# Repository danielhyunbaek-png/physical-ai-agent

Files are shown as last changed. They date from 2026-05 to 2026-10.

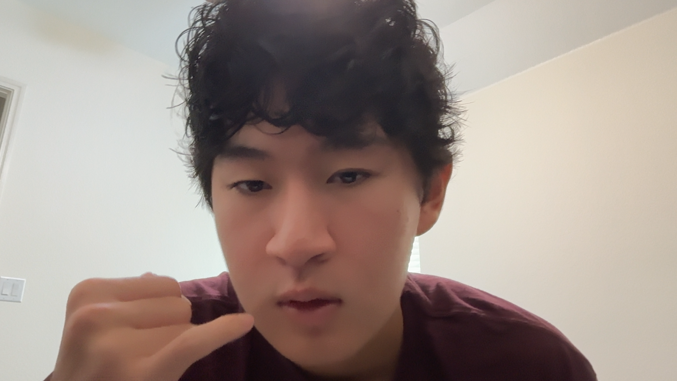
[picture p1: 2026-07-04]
agent/test_frame.png

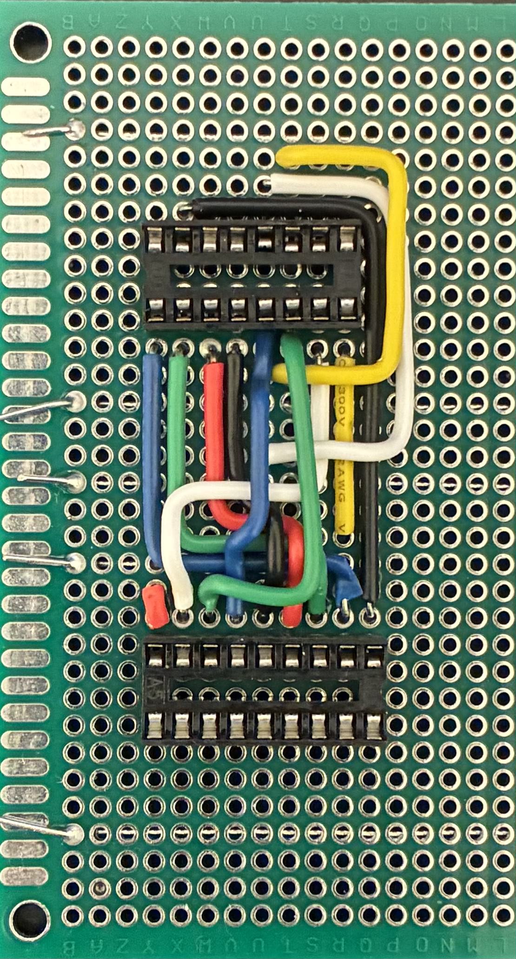
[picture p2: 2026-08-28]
cell1photo.jpg

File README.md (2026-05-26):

Architecture:

The Physical AI Agent I'm currently building is a closed loop system that is made to operate a computer exactly how a human does. It uses visual feedback and physical actuations. The system runs on a discrete time loop across a macOS host and two microcontrollers.

Vision:

- Uses a fixed webcam
- Python based pipeline will capture frames at 30 fps. Each frame is deskewed using a precomputed perspective transform to map the MacBook screen to a fixed 1920x1200 pixel grid. 
- Uses OpenCV template matching for UI elements and Tesseract OCR for text extraction. 

Cognition: 

- Runs on the MacBook Pro
- Python FSM that reads perception stream and executes serial commands. 
- Goal: Under 100 ms from screen change to first physical actuation. 

Action:

-Keyboard: Using the Nuphy Air75 v3 keyboard with Blush Nano switches (45g force, 1.4 actuation).
Using the Arduino mega 2560 with 84 12V micro solenoids (10mm stroke, 5N force), housed in a custom 3D printed matrix plate. 11 cascaded 74HC595 shift resistors feeding 11 ULN2803A Darlington arrays. All powered by 12V PSU with a firmware cap of 12 solenoid activations. 

Mouse: 2 axis XY gantry system controlled by Arduino Uno. Powered by NEMA 17 steppers driven by A4988 drivers. Two SG90 hobby servos providing click actuation.

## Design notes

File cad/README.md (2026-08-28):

# cad/ — Fusion scripts

Fusion has no MCP connector, so CAD works the same way KiCad does: **Daniel
drives Fusion, Claude owns the file and verifies it mechanically.** These
scripts are the mechanism — geometry lives in Python, so every dimension is
reviewable, diffable, and checkable without opening Fusion.

| File | What it does |
|---|---|
| `fusion_groove_coupon.py` | Builds the brief-08 groove coupon (plate section + 2 walls + mini-deck) in a fresh Fusion document. **The teardown gate.** |
| `verify_coupon_geometry.py` | Runs outside Fusion. Asserts every brief-08 invariant, the Jul 27 measurements, CSV key positions, and cross-checks against `Air75_84Key_Plate_Left.stl`. Currently 0 failures. |

## Running the coupon script in Fusion

1. Open Autodesk Fusion. Any document — the script creates its own.
2. **Utilities** tab → **ADD-INS** panel → **Scripts and Add-Ins** (or `Shift+S`).
3. **Scripts** tab → the **+** beside "My Scripts" → **Create from existing** → pick
   `cad/fusion_groove_coupon.py` from this repo.
   *(If Fusion insists on copying it into its own scripts folder, use the green
   `+` → "Link" option so it keeps reading the repo copy and git stays the source
   of truth.)*
4. Select `fusion_groove_coupon` → **Run**. A dialog reports the key dimensions.
5. Four components appear at true assembly coordinates: `Coupon_Plate`,
   `Wall_A`, `Wall_B`, `Coupon_Deck`. **Look at it first** — the walls should sit
   in their plate grooves with the deck grooves capturing their tops.
6. Export each component: right-click component → **Save as Mesh** → STL, or
   **File → Export** → STL with "one file per body" unchecked.

## Verifying before you print

```
python3 cad/verify_coupon_geometry.py
```

Needs `trimesh` and `numpy` for the STL cross-check (`pip install trimesh numpy`);
everything else runs on stock Python. Exit code 0 = all invariants hold.

## Slicer notes

| Part | Orientation | Notes |
|---|---|---|
| `Coupon_Plate` | flat, as modelled | groove floor is only 2mm — don't skimp on top layers |
| `Wall_A` / `Wall_B` | **lay flat on the wide face** | 58mm tall × 2.5mm thin section; printing upright makes a fragile fin and puts layer lines across the load path |
| `Coupon_Deck` | flat | grooves face up or down, doesn't matter at 2mm |

Same material and same nozzle/layer settings as the 84-key plate print — the
whole point is that the groove fit transfers to the real part.

## The test sequence (brief 08 §Stage 1 item 7)

1. Heat-set an M3 insert into each wall's boss.
2. Screw one solenoid to each wall **on the bench** — full access, no slot-driving.
   Use the M3×3 flat heads, counterbores facing the back.
3. Drop each wall+solenoid into its plate groove, plungers entering their Ø10
   holes first. Check: does the datum face seat? Does the groove bind or rattle?
4. Mini-deck on, 2 × M3×8 down into the inserts.
5. **Check the flare clears the back row's spring** — Wall_A's flare passes
   within 1.0mm of Wall_B's solenoid spring. This is the one clearance derived
   from an estimated spring OD rather than a measurement.
6. Fire both solenoids off the breadboard driver, deck installed.
7. One full swap cycle: deck off, wall out, swap the solenoid, back in.

**Pass = the old plate teardown is authorised.** Fit fail = change
`GROOVE_CLEARANCE` at the top of the script by ±0.05–0.10, re-run, reprint the
coupon only.

## Tuning log

Record each printed value here so the winning number is never re-guessed.

| Date | `GROOVE_CLEARANCE` | Plate groove | Deck groove | Result |
|---|---|---|---|---|
| — | 0.25 | 2.75 | 5.30 | not yet printed |

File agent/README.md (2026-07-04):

# Agent software — observe → decide → act

The complete software stack for the physical agent, every layer testable
**without any hardware** (campsite rule, July 2026: exercise everything on
the MacBook alone, then point it at the real rig at home).

| File | What | Hardware needed |
|---|---|---|
| `keyboard_driver.py` | Python wrapper for the `keyboard_v1` serial protocol | None (dry-run) → Mega later |
| `mouse_driver.py` | Mouse backends: dry / **mousekeys** / gantry | mousekeys needs only the keyboard! |
| `actions.py` | One action vocabulary: validation + dispatch | None |
| `vision.py` | Capture → rectify → template match + OCR + frame hashing | Mac camera, or `still=` a PNG |
| `llm.py` | Pluggable brain + retries + JSON repair + $ metering | None |
| `runtime.py` | Session engine: logging, budgets, stuck detection, escalation | None |
| `agent_loop.py` | General-goal CLI over the runtime | None (`--dry-run --scripted`) |
| `calibrate.py` | screen / tft / gantry / mousekeys calibration flows | Varies |
| `tft/` | TFT layer: layout, set data, semantic actions, `play_tft.py` | None to rehearse |
| `tests/run_tests.py` | 20-test ladder for all of the above | **None at all** |

## The one command that proves the plumbing

```bash
cd agent && source .venv/bin/activate
python tests/run_tests.py        # 20 tests, no hardware, no network, no keys
```

If that passes, what's left to trust is physics and prompt quality.

## Choosing a brain (`--provider`)

| Provider | Cost per ~700-turn TFT game | Needs |
|---|---|---|
| `ollama` | $0 (local Qwen3-VL) | `brew install ollama && ollama pull qwen3-vl:8b` |
| `gemini` / `deepseek` / `qwen` | ~$0.10–0.50 | API key env var (see `llm.py` header) |
| `anthropic` | ~$4–8 | `ANTHROPIC_API_KEY` |

Strategy: **develop on `ollama`, play on cheap cloud, escalate hard turns.**
`--escalate-to anthropic` lets the cheap brain hand up any turn it flags with
`"escalate": true` (augment choices), and `--budget-usd 1.00` hard-stops the
session at the estimated spend.

## Choosing a mouse (`--mouse`)

| Backend | What moves the cursor | Hardware |
|---|---|---|
| `none` (default) | nothing — keyboard-only goals | Wave 1 |
| `dry` | print statements | none |
| `mousekeys` | **macOS Mouse Keys pressed by the solenoids** | Wave 1 only! |
| `gantry` | XY gantry + click servos (`firmware/mouse_gantry_v0`) | Wave 2 |

`mousekeys` is the sleeper: enable Mouse Keys on the target Mac
(Accessibility → Pointer Control; also enable the 5×-Option toggle) and the
robot gets real clicking and dragging **before any Wave 2 hardware exists**.
The driver toggles Mouse Keys off around text input automatically. Calibrate
speeds with `python calibrate.py mousekeys`.

## Run recipes

```bash
# plumbing, zero everything
python agent_loop.py --goal test --scripted --dry-run --mouse dry

# real brain, no hardware, on a saved screenshot
python agent_loop.py --goal "describe the screen" --dry-run \
    --still shot.png --provider ollama

# real rig, general goal
python agent_loop.py --goal "open spotlight and type hello" \
    --port /dev/tty.usbmodem14101 --calib calibration/screen_quad.json

# TFT rehearsal (no hardware) / TFT for real (cheap + escalation + cap)
python tft/play_tft.py --still tft_shot.png --dry-run --provider ollama
python tft/play_tft.py --port /dev/tty.usbmodemXXXX --mouse gantry \
    --mouse-port /dev/tty.usbserialYYYY --mouse-calib calibration/gantry_affine.json \
    --provider gemini --escalate-to anthropic --budget-usd 1.00
```

Every session writes `logs/session_<ts>/` — `session.jsonl` (plan, actions,
results, cost per turn), the frame each decision saw, and `summary.json`.
That's the replay data for prompt tuning.

## Before real TFT games (checklist)

1. `python calibrate.py screen` — C920 on tripod, bright fullscreen page.
2. `python calibrate.py tft --still <screenshot>` — nudge `tft/layout.json`
   until the dots sit on the shop cards/hexes/buttons.
3. Fill in `tft/set_data.json` for the live set (file explains how).
4. Crop a combat-only UI element into `tft/templates/combat_marker.png` —
   unlocks combat-phase skipping (~70% fewer LLM calls).
5. Mouse: `calibrate.py gantry` or `calibrate.py mousekeys`.

## Setup

```bash
cd agent
python3 -m venv .venv && source .venv/bin/activate   # re-activate EVERY terminal
pip install -r requirements.txt
brew install tesseract        # OCR engine (macOS)
```

### MAP workflow (ties into the solder-time log)

Keep logging `cell,out,key` lines at solder time (MAP discipline: label holes,
not wires). Put them in a CSV, then:

```python
from keyboard_driver import KeyboardDriver, load_map_from_log
kb = KeyboardDriver("/dev/tty.usbmodem14101")
load_map_from_log(kb, "map_log.csv")   # pushes MAP entries + SAVEs to EEPROM
kb.walk()                              # verification pass: watch which key clicks
```

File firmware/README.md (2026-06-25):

# Firmware — Week 2 Breadboard

Two sketches. Build them in order. Each is its own folder so the Arduino IDE is happy.

## 1. `sr_led_walk/` — sanity-check the shift register

Goal: prove one 74HC595 is wired correctly with 8 LEDs before any solenoids exist.

Wiring (74HC595 → Arduino Mega):

| 595 pin | Name  | Goes to |
|---:|---|---|
| 14 | DS | D11 |
| 11 | SH_CP | D12 |
| 12 | ST_CP | D13 |
| 13 | OE | GND |
| 10 | MR | +5V |
| 16 | VCC | +5V (+ 0.1 µF to GND) |
|  8 | GND | GND |
| 15, 1–7 | Q0–Q7 | LED → 330 Ω → GND |

Flash, open Serial Monitor at 115200 — you should see a bit walking left-to-right across the 8 LEDs once per second-ish.

## 2. `keyboard_v0/` — drive 4 solenoids

After the LED walk works, swap the LEDs for the ULN2803A → 4 solenoids.

ULN2803A wiring:

- IN1–IN8 ← 595 Q0–Q7 (one-to-one)
- OUT1–OUT8 → low side of each solenoid coil
- Solenoid high side → +12V rail from PSU
- **COM (pin 10) → +12V** (this enables the internal flyback diodes — do not skip)
- GND (pin 9) → PSU GND **and** Arduino GND (common ground star point)
- 470 µF (or larger) bulk cap across the 12V rail near the ULN
- 0.1 µF decoupling across the 595 VCC/GND

Critical: the Arduino 5V rail and the PSU 12V rail must **not** touch. Only the grounds tie.

Open Serial Monitor at 115200 baud, line ending: Newline. Then type:

```
FIRE 0 50
FIRE 1 50
FIRE 2 50
FIRE 3 50
```

Acceptance: 4 crisp clicks in order. Plungers fully retract between fires. No buzzing, no missed clicks.

Also available: `ALLOFF` (force every channel low — useful if a fire hung).

### Pulse-width tuning notes

- 50 ms is the walkthrough default. Try also 30 ms and 80 ms and listen — Blush Nano switches actuate at ~1.4 mm so 30 ms is often enough once geometry is right.
- The firmware clamps any pulse to 200 ms and enforces a 20 ms gap between fires as a coil-protection guardrail.

### What to measure while the breadboard is live (feeds Week 3 CAD)

1. **Mounting tabs** — confirm 2 vs 4 tab layout and tab-hole spacing (calipers).
2. **Plunger rest extension** — mm of plunger sticking out at rest.
3. **Plunger force at 30 / 50 / 80 ms** — push against a kitchen scale tared to zero.
4. **Body temperature** after firing one solenoid 200× at 50 ms with 100 ms gap. Touch test is fine for now; flag if uncomfortably hot.
5. **End-to-end latency** — toggle a free Mega pin HIGH right before the latch and LOW after, scope or logic-analyzer the pin vs the solenoid current rise (optional, nice to have).

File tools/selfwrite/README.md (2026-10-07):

# selfwrite: the keyboard writes its own software

From the 698-like comment: *"Now let Claude control it and write its own software."*

`gen0.py` (written by a human) asks Claude to write `gen1.py`. **The solenoids type gen1 into Terminal**, then type `python3 gen1.py &`. gen1 now controls the keyboard: it asks Claude for gen2, types it and launches it. **gen3 is the last one** and says goodbye. Each generation gets a GOAL from its parent and has to do one new visible thing.

Safety rails live in `selfwrite.py`, which Claude can't edit:
- Hard stop at gen 3.
- Generated code can only import `selfwrite`, with no os, files or network.
- Code is syntax-checked before it's typed.
- Every typed file is **read back from disk and compared** before it runs.

## 0. One-time setup (~5 min)
```bash
cd ~/"Documents/Claude/Projects/Physical AI Agent/agent" && source .venv/bin/activate
python3 -c "import serial; print('pyserial ok')"
export ANTHROPIC_API_KEY=sk-ant-...     # console.anthropic.com -> API keys
cd ../tools/selfwrite
python3 selfwrite.py preview            # NO typing: prints the gen1 Claude would write
```
If `preview` prints Python code, the API key works.

## 1. Map the keys Python needs (~30–45 min, PSU on only while testing)
```bash
python3 selfwrite.py check              # lists mapped keys + what's missing
```
**Must have:** `Enter LShift 9 0 ; = ' . , -`. All of these are needed for `( ) : = " ' . , _`.
**Should have:** `1–8`, `[ ]`, `/`. Claude is told which characters exist and will avoid the rest.
To map a key: Serial Monitor, `FIRE <ch>`, watch which key moves, then `MAP <ch> <Name>` and `SAVE`. Run `check` again when you're done.
Then a smoke test: open a blank Terminal and type `python3 -c "print('hi')"` with `TYPE` and `KEY Enter`.

## 2. Film
1. Close Serial Monitor and the Monkeytype Chrome tab. They hold the USB port.
2. Use a clean Terminal window with a big font (Cmd +), in `tools/selfwrite` with the venv active. Run `rm -f gen1.py gen2.py gen3.py`.
3. Type yourself: `python3 gen0.py &` and press Enter. **Then hands off.** Keep the Terminal window focused the whole run.
4. Each generation takes about 1–2 min of typing plus 10–20 s for Claude. Total is roughly 5–7 min, so speed it up in the edit.

**If it stops:** `[selfwrite] ... differs` means a key was missed, usually from plate sag. It retries once, then stops. If the shell is stuck in `heredoc>`, press Ctrl-C by hand. For the shot list, the `gen1.py`–`gen3.py` files are the evidence. Open them at the end of the video.

## Env knobs
`CLAUDE_MODEL` (default `claude-sonnet-5-5`) · `KB_PULSE` (50) · `KB_PORT` · `SELFWRITE_MAX_GEN` (3) · `KB_DRY=1 SELFWRITE_FAKE=1 python3 gen0.py` runs the whole chain with no hardware and no API.

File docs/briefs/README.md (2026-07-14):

# Task briefs — pre-loaded prompts for upcoming milestones

Each brief is a ready-to-run session starter written by Fable 5 (July 2026) with full project context baked in. When a session's goal matches a brief, read the brief FIRST — it encodes constraints and failure modes that took weeks to learn.

| Brief | Milestone | Blockers |
|---|---|---|
| `01_cell1_solder_and_first_fire.md` | Solder driver cell #1, cold-continuity gate, first fire from soldered board | Home + hardware |
| `02_walk_map_verification.md` | Flash keyboard_v1, build the MAP via solder-time log, verify with WALK | Cell #1 done |
| `03_84key_plate_cad.md` | Full 84-key plate CAD (the big one) | 2×2 FIRE test passed |
| `04_wave2_mouse_decision.md` | Pick the Wave 2 mouse mechanism (TFT drag requirement) | None — do anytime |
| `05_tft_bringup.md` | First TFT game: calibration → set data → cheap-brain game | Vision + mouse working |
| `06_driver_pcb.md` | Custom driver PCB (replaces perfboard for all 11 cells) + interim breadboard fire test | None — design now, breadboard this week |

Always pair a brief with `docs/PLAYBOOK.md` (reasoning patterns) and CLAUDE.md (current facts). If a brief contradicts CLAUDE.md, CLAUDE.md is newer — trust it and fix the brief.

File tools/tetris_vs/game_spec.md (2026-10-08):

Write a complete two-player VERSUS Tetris game in ONE Python file.

Context: you are playing against a human, the person who just spoke to you. Every
character of your file will be typed by a physical robot keyboard (84 solenoids
pressing real keys), then run. During the game YOU play too, but you can only
act by pressing real keys through those same solenoids, so every move you make
is physically slow and a press can occasionally be missed. Design for that.

## Hard rules (a test harness enforces these)
- Python 3.9. Allowed imports ONLY: pygame, random, math, time, robot.
- ASCII only. 4-space indents, no tabs. Keep lines under 80 characters.
- Keep it SHORT: aim for 7000-8500 typed characters, hard limit 9500
  (leading indentation is free: the editor auto-indents). Each character
  costs the robot ~0.12 s of typing. Very few comments.
- No file, network or OS access. Fonts: pygame.font.Font(None, size) only.
- The window: screen = pygame.display.set_mode(robot.WINDOW)
- Call robot.tick() exactly once per frame in the main loop. 60 FPS clock.
- QUIT event or the Escape key exits cleanly (pygame.quit(), then return).

## The robot module (already exists, do not write it)
    import robot
    robot.WINDOW            # (width, height) for set_mode
    robot.press(key)        # key is one of "J", "L", "I", "K", "Space".
                            # Queues ONE physical key press. Returns True if
                            # queued. Never blocks.
    robot.pending()         # number of presses queued or still in flight
    robot.say(text)         # speaks text out loud in Claude's voice; skipped
                            # (returns False) if it is already talking
    robot.tick()            # once per frame
    robot.report(name, value)   # status for the test harness, see below

## Controls (two keyboards feed the same Mac, so the keys MUST differ)
- HUMAN (left board, Mac's built-in keyboard): Left/Right arrows move,
  Up rotates clockwise, Down soft-drops one row, Right Shift OR Return
  hard-drops.
- CLAUDE (right board, the robot keyboard): J left, L right, I rotate
  clockwise, K soft drop one row, Space hard drop.
- The game moves Claude's piece ONLY when it receives those KEYDOWN events,
  exactly like a human player. Your AI must never move pieces directly.

## Game rules
- Two 10x20 boards. Standard 7 tetrominoes, colored.
- Both players get the SAME piece sequence: one 7-bag sequence per match
  from random.Random(seed), each player has their own index into it.
- Spawn at the top center. Rotation with simple wall kicks (try x offsets
  0, -1, 1, -2, 2). A piece locks when gravity cannot move it down.
- Gravity starts at 0.8 s per row and gets 20% faster every 30 s (min 0.1 s),
  same for both players.
- Clearing n lines: n >= 2 sends n - 1 garbage rows to the opponent (4 lines
  sends 4). Garbage rows are gray, full except one random gap, and are added
  at the bottom of the opponent's board when their next piece spawns.
- If a new piece cannot spawn, that player tops out and the OTHER player wins.

## Screens
- Menu: big title "HUMAN vs CLAUDE", the controls for both players,
  "click to start". A mouse click starts a 3-2-1 countdown, then play.
- Play: HUMAN board on the left, CLAUDE board on the right, names above them,
  lines cleared, next-piece preview for each, match timer in the middle.
- Game over: a big "CLAUDE WINS" or "HUMAN WINS" overlay plus
  "press R for rematch". R starts a new countdown with a new seed and keeps a
  running match score (e.g. "HUMAN 1 - 3 CLAUDE").

## Claude's player (the important part)
- When Claude's piece spawns, pick a placement: for every rotation and every
  x, simulate a hard drop on the current board and score the result with
  -0.51*aggregate_height + 0.76*lines_cleared - 0.36*holes - 0.18*bumpiness.
  Prefer fewer rotations on ties.
- Then each frame: if robot.pending() > 0, or less than 0.2 s has passed since
  your last press, do nothing. Otherwise look at the ACTUAL piece state and
  press exactly one key toward the goal: "I" until the rotation matches,
  then "J"/"L" until x matches, then "Space".
- Never assume a press worked: always decide from the actual state, so a
  missed press is simply repeated and an extra move is corrected. If the
  same press has had no effect 4 times in a row (blocked), press "Space".
- Re-plan whenever a new piece spawns (track a piece counter).

## Trash talk (robot.say)
Write your own short, funny, PG lines (under 12 words each), several
variants per moment, picked at random:
- when the match starts,
- when Claude clears 2+ lines (sending garbage),
- when Claude clears 4 lines at once,
- when the human tops out (Claude wins),
- when Claude tops out (the human wins; be a gracious but salty loser).
Keep it general: call the opponent "human", never use a name, and never
mention who built the robot or anything about its history. Human-vs-machine
banter, and jokes about you moving only by solenoid, are fine.

## Reports for the test harness (required)
    robot.report("state", s)        # s in "menu","countdown","playing","over"
    robot.report("claude_lines", n) # total lines Claude cleared this match
    robot.report("daniel_lines", n)
    robot.report("winner", w)       # "CLAUDE" or "HUMAN", when a match ends

Reply with ONLY the Python code. No markdown fences, no explanation.

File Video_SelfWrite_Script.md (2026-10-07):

# Video: "The keyboard writes its own software" (Oct 6, 2026)

Uses the hook framework: two questions in the hook, answer #1 right away, "but it's not what you think" instead of explaining, real stakes, and a new question at every generation.

## Hook (0–4 s)
VO: "You told me to let Claude control my self-typing keyboard. So now it writes its own code, types it, and runs it."
- **Question 1:** "Can it actually do it?" Answer it immediately: hard cut to solenoids typing code, with the Terminal filling up.
- **Question 2:** "But can it survive 3 generations without one mistake?" Leave it open until the end.

## "But it's not what you think" (4–10 s)
VO: "Everyone in my comments said 'just use a macro.' But this isn't a macro. A macro replays keys someone recorded. Nobody knows what this code says, not even me, until Claude writes it."

## Stakes (10–18 s)
- "One missed keypress is a syntax error, and the whole chain dies."
- "That's about 1,500 keystrokes in a row with zero mistakes, on a plate that sags in the middle."
- "And the last time I left this thing running on its own, it melted a chip." (Show the dead ULN2803A if you still have it.)

## Body: a new question every generation (18–50 s)
- On screen the whole time: `GEN 1/3` and a keystroke counter.
- Before each launch: freeze frame plus "What did Claude make it do?" Then play the result.
- Gen 1 → its new thing. "Then it wrote its own replacement."
- Gen 2 → its new thing. "One more."
- Gen 3 (the last one) → close-up as it types. "Did it make it?"

## Payoff (50–60 s)
- Gen 3's goodbye on screen. Then open gen1–gen3.py side by side: "Nobody touched these keys."
- Close with a comment prompt: "It stopped at gen 3 because I told it to. Should I take the limit off?"

## Honest notes
- If a generation fails on camera, **keep it.** "It died on keystroke 1,102" is a real stake paying off, and it sets up a sequel.
- Don't claim it's dangerous beyond what's true. Its code can't touch your files or the internet; you set it up that way. "I put it in a box" is a good line if comments ask.

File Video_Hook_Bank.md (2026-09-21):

# Video Hook Bank — the comeback video (and every one after)
**Built Sep 21, 2026.** Research-backed hook options matched to footage actually in hand.
Companion to `Video_Scripts.md` and `Social_Media_Strategy.md`. Supersedes the hook line in `Video_Script_Big_Reset.md` (that video posted Jul 30).

---

## What the research actually says

Most "viral hook formula" content online is SEO filler with no data behind it. Two findings survived filtering, and both point the same direction:

1. **"Result First" is the strongest hook type in DIY/Maker specifically** — 84 avg retention score vs 58 for the worst type in the same niche, a 26-point gap. Across all niches it ranked #1 of 8. (Brightbean, 10k-hook analysis. Proprietary scoring, so treat as directional — but it converges with everything else.)
2. **Deliver the complete hook inside 5 seconds.** Videos that did retained ~23% more viewers at the 30-second mark than videos needing 10+ seconds of setup.

Supporting, weaker: blended hooks (two types at once) beat single-type 79 vs 73. And the recurring failure mode across analyses is *setup before claim* — backstory, credentials, context, "so last video I…".

**All of this already agrees with `Social_Media_Strategy.md`:** *"0–2 sec: Visual hook. Show the most impressive thing first. NO intro, NO 'hey guys.'"* The research doesn't change the playbook, it confirms it and tells us which specific asset to lead with.

---

## The structural consequence — this is the important part

"Result First" in a build series that **isn't finished yet** means: open on the most finished-looking working thing you own.

That is the **breadboard fire-test clip** — a solenoid physically pressing a key, a character appearing on screen. It is the only footage in the archive where the machine does the thing.

**So it goes at 0:00, not only at 0:40.** Use it twice:

- **0:00–0:02** — the press, real sound, no music, no talking. Proof before claim.
- **0:02–0:05** — the hook line lands over it or immediately after.
- ...build content...
- **0:38–0:48** — the fuller version of the same clip as the payoff, now that the viewer knows what it cost.

Same shot, two jobs. Opening cold on a black screen or a face is spending the first two seconds on the least interesting frame you have.

---

## HOOK BANK

Each one is tagged with the pattern it copies and the shot it plays over. Every hook should be **spoken AND on-screen as text** — most viewers are sound-off on the first watch.

### Tier 1 — lead with these

**H1 — "This keyboard types by itself."** · *Result First* · over the fire-test press
> Then, after the beat: *"Well — one key does. So far."*

The chosen line, tightened. Present tense beats "is going to" — a promise is weaker than a claim you're about to prove, and you can make the claim honestly because the clip is playing while you say it. The walk-back in the second line is the hook's engine: it converts a flat statement into an open loop (*how far off is he?*) and it's honest, which the rest of the video has to be anyway. Blended: Result First + a soft contrarian turn.

**H2 — "That was a robot pressing that key. I need 83 more."** · *Result First + Shocking Stat* · over the fire-test press
The number does the work without jargon, and it arrives *after* the viewer has already seen one work — so 83 reads as scale, not as noise. Strongest pure-numbers option.

**H3 — "One key down. Eighty-three to go."** · *Result First* · over the press, hard cut to the full plate on the dorm desk
Shortest in the bank — lands in about 1.5 seconds, well inside the 5-second rule, and the cut to 84 solenoids IS the punchline. Best option if you want the song to drop early.

### Tier 2 — strong, different flavor

**H4 — "There's a way to do this in software in about four lines of code. I'm not doing that."** · *Contrarian Claim* (#2 overall in the research) · over the plate overhead
This is the "why" from `Social_Media_Strategy.md` weaponized as a hook instead of buried as an explainer. Pre-empts the top comment, which makes the comments section argue *with each other* instead of with you. Use when you want the thoughtful-engineering audience over the spectacle audience.

**H5 — "Every single key on this keyboard is getting its own robot."** · *Direct Promise* · over a slow push across the populated plate
No jargon, no number required, instantly legible to someone who has never seen the project. The safest cold-start hook for a brand-new viewer — and after 7 weeks off, most of your reach is brand-new viewers.

**H6 — "233 solder joints. That's one board. I need three."** · *Shocking Stat* · over the bare PCB before-shot
Sets up the timelapse better than anything else here, because it makes the viewer want to watch the work rather than skip it. Downside: opens on effort rather than result, which is exactly the trade the research penalizes. Use it as the *second* beat at 0:05, not at 0:00.

### Tier 3 — the gap, handled

**H7 — "Last time you saw this it was a pile of wires on my desk. It's now a pile of wires 900 miles away."** · *Story Setup* · over the dorm desk wide
Addresses the 7-week absence and the move in one line without apologizing. Only use if the dorm-desk frame is genuinely good. Story Setup ranked #3 of 8 — respectable, but it spends the opening on you instead of the machine.

**H8 — "I moved to college and the first thing I unpacked was this."** · *Story Setup* · dorm desk, plate revealed
The salvageable version of the line you rejected. Works because the reveal carries it; the words alone are nothing. Weaker than Tier 1 for reach, better than Tier 1 for the people already following.

### Rejected — do not use

- **"I brought 84 solenoids to college."** Jargon in the first 3 seconds. "Solenoid" means nothing to a cold viewer, so "84" has no weight, and the sentence is about logistics rather than the machine.
- **"How do you make a keyboard type by itself?"** Question hooks ranked mid-pack (#5) and this one has no stakes — it invites the viewer to answer "you don't" and scroll.
- **Anything opening with "Part 6" / "Day 53" / "so in my last video."** Setup before claim, the single most-cited failure across every analysis. New viewers read it as "you've missed something" and leave.
- **"Everyone else brought a mini fridge."** Funny, but it's Identity Callout (#6) and it makes the video about dorm life instead of the build.

---

## Rules that apply regardless of which hook wins

1. **Hook complete by 0:05.** No exceptions. The 23% retention delta is the largest single number in this research.
2. **Real sound on the key press. Always.** Trending audio over the one moment a solenoid fires is the worst available edit — `Social_Media_Strategy.md` §The Audio Advantage is right that the sound is the competitive moat. Duck the music to zero for those 2 seconds and bring it back.
3. **Hook as on-screen text too**, not just VO.
4. **The number is 84 solenoids**, not 88. (88 = channel count including 4 spares.)
5. **Series numbering goes in the caption and title, never the first 3 seconds.**
6. **One promise per video, paid inside the same video.** The Jul 30 post ended on a 6-day countdown that went 53 days — don't write another closer you can't cash.

---

## Recommendation

**H1, with the fire-test clip cold-opening underneath it.**

It's the line you already picked, it's the top-performing pattern in your exact niche, the walk-back makes it honest and opens a loop, and it needs zero context from the previous six videos — which matters more than usual, because after seven weeks off most of the audience seeing this will have never seen the project before.

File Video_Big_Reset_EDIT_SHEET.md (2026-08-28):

# BIG RESET — VO ↔ B-ROLL EDIT SHEET
**Source script:** Daniel's Jul 28 VO revision · **Companion:** `Video_Script_Big_Reset.md`
**Runtime estimate:** ~62s at a natural pace (~2.9 words/sec). Target was 55–65s — you're at the top end. Trim candidates flagged with ✂.
**Assets already rendered:** `media/new_plate_broll_vertical.mp4` (10.7s loop), `media/new_plate_exploded_still*.png`

Timecodes assume you start on the first word. Shift everything if you add a cold-open beat.

---

## 0:00 – 0:05 · LINE 1

> "This one cell drives 8 solenoids — so 8 keys on my robot keyboard."

| Phrase | Shot |
|---|---|
| "This one cell" | **HOOK — cell #1 in hand, slow rotate, good light.** Hold this one shot for the whole line. Don't cut. |
| "drives 8 solenoids" | Optional 0.5s insert: finger points at the two chips |
| "so 8 keys on my robot keyboard" | Whip to the populated plate, or stay on the cell |

**On-screen text:** `1 cell = 8 keys`

> ⚠️ **Your hook is now a technical statement.** The earlier draft opened with "took me 4 hours to solder, and honestly, it looks very pretty" — pride before the fall, which is what makes the next 50 seconds land. Consider adding it back as a 3s cold open before this line.

---

## 0:05 – 0:13 · LINE 2

> "If I want it to drive 84 solenoids, I need 11 of these chips, that's over 170 wires and 700 joints I need to solder"

| Phrase | Shot |
|---|---|
| "If I want it to drive 84 solenoids" | Wide/overhead of the fully populated plate — all 84 mounted |
| "I need 11 of these" | Cut back to cell #1, or lay 11 perfboards/chips out on the desk |
| "over 170 wires and 700 joints" | **Cell #1 soldering clip (footage on hand), speed-ramped hard** |

**On-screen graphic (the credibility beat):** `170+ wires · 700+ joints · 25+ hrs` — hits on "700 joints," stays up ~2s

> ⚠️ **Fix before you record: "11 of these chips" is wrong.** Each cell is *two* chips — a 74HC595 shift register and a ULN2803A driver. 11 cells = 22 chips. Say **"11 of these"** or **"11 of these cells."** A commenter will catch this.

---

## 0:13 – 0:23 · LINE 3

> "Instead of doing that, I decided to design a custom PCB instead. All those wires just become copper traces printed on the board, and every cell comes out identical."

| Phrase | Shot |
|---|---|
| "I decided to design a custom PCB" | **KiCad screen recording** — slow pan across the routed board. Record fresh; it's DRC-clean and final |
| "all those wires just become copper traces" | The money shot: KiCad 3D viewer rotating, or the Freerouting autoroute replay if you still have it |
| "every cell comes out identical" | Zoom on the 4 identical cells in a row, then **JLCPCB order confirmation** (blur address/payment) |

**On-screen graphic:** the wire/joint numbers strike through → `$40 · 2 weeks`

> ✂ **Trim option:** "Instead of doing that... instead" is doubled. Cut to *"So instead, I designed a custom PCB."* Saves ~1.5s.
>
> 📌 **Number check:** bare boards were ~$10–20 for 5 from JLCPCB. `$40` is fine if you're counting terminals + sockets, but the lower number is a stronger flex if you want it.

---

## 0:23 – 0:34 · LINE 4

> "Speaking of problems to fix, the current wiring on my plate is a complete mess. Trying to organize over 168 wires through these thin walls is going to be a pain in the ass."

| Phrase | Shot |
|---|---|
| "the current wiring on my plate is a complete mess" | **Wide/overhead of the plate with the tangle fully visible.** Shoot this BEFORE Phase 0 tip-snipping — the mess is the argument |
| *(one second of silence)* | **Hold. Deadpan.** This is the comedic beat — let the shot breathe |
| "over 168 wires through these thin walls" | Low-angle close-up down the wall slot, leads crossing everywhere. Slow push-in |
| "pain in the ass" | Cut to your face, or a hand giving up on a bundle |

**On-screen text:** `168 leads · 6 walls · 16.55mm slot`

---

## 0:34 – 0:43 · LINE 5

> "Another problem is repairability. Because the rows can only screw from front to back, swapping one solenoid in the middle means unscrewing every row behind it"

| Phrase | Shot |
|---|---|
| "Another problem is repairability" | Close-up: finger taps an interior-row solenoid |
| "the rows can only screw from front to back" | Macro on a counterbored screw head, then pan showing the head pointing into the next body |
| "swapping one solenoid in the middle" | Same finger taps the middle solenoid again |
| "means unscrewing every row behind it" | **Slow pan across all the rows behind it.** Optional: back one screw out with the driver (tease, don't tear down) |

**On-screen text:** `swap 1 → unscrew 3 rows`

> 📌 The teardown gate is still the groove coupon. One screw out is the honest amount of tease.

---

## 0:43 – 0:51 · LINE 6

> "That's why I designed a new plate which has interchangeable walls, and a top deck where my PCB will sit, so the wires run straight up."

**This is the render.** `media/new_plate_broll_vertical.mp4` — it's a seamless loop, so start anywhere.

| Phrase | Shot (timecode into the clip) |
|---|---|
| "That's why I designed a new plate" | Clip ~0:00 — assembled, slow orbit |
| "which has interchangeable walls" | Clip ~3:00–5:00 — the six wall modules fanning out into the staircase. **The orange one is the callout** |
| "and a top deck where my PCB will sit" | Clip ~1:00–2:00 — the deck lifting away with the 3 green boards on it |
| "so the wires run straight up" | Hold on the exploded state — the 84 vertical leads read clearly. Optional freeze on `new_plate_exploded_still_labeled.png` |

**On-screen text:** `removable walls · top deck · wires straight up`

> If you'd rather not use the render for the whole line, cut the last phrase to the real plate and gesture upward. But the render is the only asset that shows the deck, which doesn't exist yet.

---

## 0:51 – 1:02 · LINE 7 (CTA)

> "This is a pretty big reset. But once the boards arrive in 2 weeks, I'm tearing down the old plate, rebuilding it, and getting all 84 keys typing on their own. Stick around."

| Phrase | Shot |
|---|---|
| "This is a pretty big reset" | **Face cam.** First time your face is on screen — that's why it lands |
| "once the boards arrive in 2 weeks" | Quick insert: JLCPCB order/shipping screen |
| "tearing down the old plate, rebuilding it" | One screw coming out with the driver |
| "getting all 84 keys typing on their own" | Back to face cam, or the wide plate shot |
| "Stick around" | Face cam, hold, cut on the word |

**End card:** `Rebuild starts when the boards land — ~Aug 9`

---

## Shot list, deduplicated (what to actually capture)

- [ ] Cell #1 in hand, slow rotate, good light — **the hook, shoot it well**
- [x] Cell #1 soldering clip — already have it
- [ ] Plate wide/overhead WITH the wire mess — **shoot before Phase 0 tip-snipping**
- [ ] Low-angle down the wall slot, leads crossing
- [ ] KiCad screen recording: 2D routed board pan + 3D viewer rotate
- [ ] JLCPCB order confirmation screenshot (blur address/payment)
- [ ] Interior-row finger tap + pan across the rows behind
- [ ] Macro of a counterbore screw head
- [ ] One screw backing out with the driver
- [ ] Face cam for the CTA
- [x] New-plate visual — `media/new_plate_broll_vertical.mp4`

## Facts checklist (all verified against the project record)

- 84 solenoids mounted, 168 tab screws, 168 leads
- 1 cell = 8 solenoids = 8 keys; **11 cells** (22 chips) for the full matrix
- ~170 wires / 700+ joints to hand-build all 11 cells; **4 hours measured** for cell #1
- PCB: 120 × 66mm, 4 cells per board, **3 boards**, 5 ordered Jul 26, ~2-week lead
- New plate: groove-sandwich removable walls, deck underside at Z58, wires straight up
- Say "84 solenoids," not 88 — 88 is the channel count (4 spares)

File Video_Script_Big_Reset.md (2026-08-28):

# VIDEO: The Big Reset
**Title options:** "I'm tearing apart a robot that works" · "84 solenoids, and I'm starting over" · "4 hours to solder one. I need 11."
**Platform:** All 4 (TikTok, Reels, Shorts, X)
**Length:** ~30 seconds
**When to post:** Now — boards were ordered Jul 26 and **arrive in ~6 days (≈ Aug 5)**, not 2 weeks. Post immediately so the closer's "6 days" is still true.
**Content pillar:** The Struggle / Pivot
**Status (Jul 30):** POSTABLE. All four shots are in hand or grabbable today: cell #1 + soldering clip, populated plate w/ wire mess, KiCad screen recording, JLCPCB order confirmation. **Cut down from 60s → 30s because the new-plate CAD/coupon footage doesn't exist yet** — the plate rebuild is now its own video (see Arc below).

---

## Script

**[HOOK — 0:00–0:05]**
*Beauty shot: perfboard cell #1 in hand, slow rotate, good light.*

> "This took me way too long to solder, and it drives 8 keys on my keyboard."

**[THE PROBLEM — 0:05–0:13]**
*Cut to the soldering clip, speed-ramped. On-screen graphic: "170+ wires · 700+ joints · 25+ hrs."*

> "But I need 84 keys, which means 11 of these cells, and that adds up to over 170 wires and 700 solder joints."

**Alt** (if you want the number to land harder): > "But 84 keys means 11 of these cells — which works out to over 170 wires and 700 solder joints."

**[THE PIVOT — 0:13–0:22]**
*Screen recording: KiCad board, traces panning. Then hard cut to the JLCPCB order confirmation. Graphic: wire/joint numbers crossed out → "$40 · 6 days."*

> "So instead, I designed a custom PCB. Every wire becomes a copper trace, and every cell comes out identical."

**[THE TEASE — 0:22–0:30]**
*Overhead of the populated plate, wire mess fully visible. Deadpan beat. Then face cam for the last line.*

> "6 days until the PCB shows up, which gives me 6 days to redesign the plate to fix this mess."

---

## Shot List

- [ ] **HOOK:** cell #1 in hand, slow rotate, good light
- [ ] **HAVE:** the 4-hour soldering clip — speed-ramp it
- [ ] Screen recording: KiCad board layout (5s of traces is plenty)
- [ ] Screenshot: JLCPCB order confirmation (blur address/payment)
- [ ] Overhead of the populated plate WITH the wire mess visible — don't tidy it, the mess is the argument
- [ ] Face cam: last line only

## Edit Notes

- **Pride before the fall.** Open on the pretty cell, then spend 25 seconds explaining why it's obsolete.
- Graphic at ~0:08: `170+ wires · 700+ joints · 25+ hrs` → hard cut to `$40 · 6 days`. The numbers are the credibility engine.
- **The $40 is now only on-screen, not spoken** — the pivot line ends on "identical," and the closer carries the timing. Cleaner, and it keeps the VO conversational.
- **The 6-day lead makes the plate rebuild the whole reason to keep watching.** The closer sets a hard deadline you're publicly on the hook for — that's the hook for video #2.
- Say "84 solenoids," not 88 — 88 is the channel count (4 spares).
- The wire-mess reveal at 0:22 is the comedic beat. One second of silence before the last line — and land "this mess" exactly on the overhead shot.
- Do NOT tear the plate down for this video — the coupon test gates the real teardown.
- Cut for this version: the repairability explanation (interior-row swap) and the new-plate reveal. **Both are the backbone of the next video** — don't spend them here without footage.

## 3-video arc

1. **This video** — the reset + the PCB order
2. **The new plate** — removable walls, top deck, wires straight up (needs CAD screengrab + printed coupon; shoot during the lead window)
3. **Boards land** — populate, WALK all 88 channels, rebuild timelapse, full-matrix fire

## Caption

```
ripping apart a robot that already works lol

way too long to hand-solder ONE driver cell. i need 11.
so: custom PCB ($40). lands in 6 days.
until then i'm redesigning the entire plate. 168 screws coming out, on purpose.
.
.
.
#buildinpublic #robotics #engineering #diy #pcb #arduino #maker
```

## Facts checklist (say these, they're all true)

- 84 solenoids mounted, 168 screws
- 1 driver cell = 8 solenoids (8 keys); 11 cells needed for the full board
- ~170 wires and 700+ solder joints to hand-build all 11 cells (8 signal jumpers × 11 = 88 wires + 84 solenoid leads ≈ 170; joints = ~344 wire ends + 374 chip pins [16/595 + 18/ULN × 11] = 700+)
- 4 hours to solder cell #1
- Custom PCB: ~$40, ordered Jul 26, **arriving in ~6 days (≈ Aug 5)**, 5 boards ordered, 3 populated (4-cell boards, 4/4/3 cells)

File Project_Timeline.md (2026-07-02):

# Physical AI Agent — Project Timeline

*The history of this build: every phase, mistake, dead end, and fix. Current-state truth lives in `CLAUDE.md` and the live docs; this file is the story of how it got there. Files retired during the July 1, 2026 folder cleanup are summarized here — their full contents are recoverable from git commit `84a796c` ("Pre-cleanup snapshot").*

---

## Phase 0 — Planning (May 2026)

- **PRD v2 + Build Walkthrough written.** 12-week summer build: a physical AI agent that types on a real Nuphy Air75 V3 (84 solenoids) and moves a real Logitech B100 mouse (Wave 2 XY gantry), watched by a C920 webcam. Budget ceiling $1,500; estimate settled around ~$1,366.
- Original spec that later died: **4× M5 standoffs** for plate mounting, and a **flat single-row/4×4 prototype**. Both superseded (see Phases 2–3).

## Phase 1 — Parts selection (May–June 2026)

- **Solenoid: JF-0530B, 12V 5N/10mm, ×100** (~$3.50/u bulk) — 84 + 16 spares. Risks logged upfront: plunger mass latency (~3–4ms), switch wear, ±20–25% force variance across the batch, thermal under endurance. Mitigations: silicone tips, 30 spare switches, USB fan, 4-unit fast-ship kit for early validation.
- **PSU: BOSYTRO 480W 40A 12V ($33)** over the cheaper Meishile 600W — BOSYTRO bundles the IEC cord. Realistic peak ~25A, so 40A is enough headroom.
- **M5 standoffs (spreadsheet row 40): skipped** — replaced by the side-rail architecture before ever being ordered.

## Phase 2 — Solenoid reality check (June 2026)

The part in hand rewrote the mounting design:

- **It's a PULL solenoid with a double-ended plunger.** Energize → ball-tip end extends. So: mount ball-tip-DOWN; rest = clear of key, fired = presses key.
- **Mounting holes are on ONE side face, axis parallel to the plunger** → the solenoid physically cannot bolt flat to a horizontal plate. This single discovery drove the whole architecture: **tilted flat plate + perpendicular mounting walls** (one per row), solenoids bolted by their side faces, plungers hanging through Ø holes.
- **Mistake: assumed the tapped holes were M2.5** because they measured 2.5mm — but 2.5mm is exactly the M3 tap-drill diameter. An M2.5 screw "threads" but spins loose (its crests only kiss the M3 valleys). **Fix: M3.** Confirmed biting June 11.
- **Test-fit cell print — three corrections in one coupon:**
  - Plunger hole **Ø7 → Ø10**: the Ø7 cleared the ball but not the screw/nut feature above it that also travels through the hole.
  - **Holes 4mm too low** (`lower_hole_z` 3 → 7): the solenoid seats flush with the plate *bottom*, 4mm higher than modeled. Lesson: **the ball's rest position is fixed by physics; the wall holes must chase it — moving holes doesn't move the ball.**
  - Wall lengthened to contain the raised upper hole.
- `wall_offset=8` validated: frame seats flat, ball drops centered.
- Structural decision: **side rails** beat 4 standoffs (rigidity, tilt baked into geometry) and full encasement (30–40h of printing, heat trap, no switch access). Tilt = 4° (spec, feet retracted); solved ONCE by tilting the whole plate; stagger (4.76mm) handled separately.

## Phase 3 — 2×2 prototype (Week 3, June 2026)

- **Scope upgraded from the walkthrough's single-row/4×4 to a 2×2** (S, D / W, E) — deliberately forcing tilt AND stagger into the prototype, the two hardest parts of the full build. A single row would have tested neither.
- Several STL iterations (V2 → v3 → V3/VFINAL → one-piece `Prototype_2x2.stl`). Printed and test-fit.
- **June redesign — two coupled problems found on the printed part, one cause:** the front wall sits in the 3.05mm gap between solenoid-body rows; at 4mm thick it overran the gap, AND the bottom-row screw heads pointed into the back body — the bottom row couldn't be fastened.
  - **Wall 4 → 2.5mm** (material off the back face only, mounting face and pitch unmoved). 3mm was tried on paper first — 0.05mm clearance, an FDM coin-flip.
  - **Screws M3×6 cap → M3×3 flat-head + 1mm flat-bottomed Ø6 counterbore** so heads sit flush and clear the back body. Tab re-measured ~1mm (was thought 1.5).
  - **Assembly order rule born: front row first**, then back row drops in past the flush heads.
  - **Gussets considered, then rejected** — firing recoil loads the wall in-plane (+Z), its stiff direction. Reversed an earlier "add gussets" call once the load path was understood.
  - Plate trimmed 158 → 148mm; legs moved in; tilt drifted 4.0° → ~4.28° — accepted (measured keycap tilt is ~4.5° anyway).
  - **Gotcha for posterity:** the `wall_thickness` parameter was never wired to the wall sketch — the value was hardcoded. Bit us once; documented forever.
- **Stroke reality:** key bottoms out at ~5mm of ball travel with ~5mm buffer left — fine by design (keycap limits the plunger; pull solenoids are strongest near seat).
- Breadboard fire tests: **PULSE ~22ms** worked well on the 2×2.

## Phase 4 — Dead end: the card-cage architecture (June 2026) ✝

- **The idea:** replace glued-in walls with *removable* ones — wall feet slip into grooves in the base plate, a screwed-down "comb lid" clamps the wall tops. Payoff: populate each wall with solenoids on the open bench, then drop the finished module in; lift any wall out for service.
- A full single-row 3-key test-coupon plan was written (groove 2.9mm slip-fit, 2.3mm foot, 0.2mm lid preload, lead-in chamfers everywhere) with a one-day CAD→print→test schedule.
- **Abandoned before scale-up.** The Week 4 split-plate brief explicitly carried the validated screw-in walls forward instead; the interior-row access problem the cage was meant to solve got a cheaper answer — **strict front-to-back assembly order + flush counterbored heads**. Lesson: the simpler, already-validated scheme beat the cleverer one; serviceability was traded for build simplicity.

## Phase 5 — Full 84-key split plate (Week 4, June 2026)

- **Knob replaced with a normal keycap** → a clean 84-key build, every position actuated identically. 16u-wide field confirmed against the 318.9mm case.
- **The seam had to be a staircase.** A straight vertical seam is geometrically impossible — stagger packs hole centers so any straight line passes within ~2.4mm of a hole center (inside the Ø10). The stepped seam jogs between rows; every hole clears by ≥9.52mm, and the steps key the halves together in X/Y.
- Halves join with **4 cross-seam bridge screws** (tab + boss, M3 heat-set inserts — correct here in PLA, unlike the solenoid tabs where the thread is in metal). 41 keys left / 43 right; both halves fit the 256mm bed with ~90mm to spare.
- **First STL pair (`Plate_Left/Right`) superseded by `Air75_84Key_Plate_Left/Right`** — the pair actually printed.
- Printed, assembled, and populated through late June; ~half the solenoids mounted by July 1 — producing the infamous wire-mess photo that kicked off the harness redesign (Phase 7).
- Per-key data preserved in `Full_84Key_Hole_Coordinates.csv` + `Layout_Map_84Key_Split.svg` (feeds the firmware key MAP).

## Phase 6 — Driver electronics (late June – July 2026)

- **Chain: Arduino Mega → 11× 74HC595 (cascaded) → 11× ULN2803A → 84 solenoids** (88 channels, 4 spare). ULN2803A = 8 Darlington channels @ 500mA with built-in flyback diodes (COM → +12V, the never-skip pin).
- Breadboard proofs first: `sr_led_walk.ino` (shift register + LEDs), then `keyboard_v0.ino` firing the 2×2.
- **Board split: 3 perfboards** (2-board layout drafted and rejected).
- Comprehensive first-time-solderer docs written (`Soldering_Plan.md`, `OneCell_595_ULN_Build_and_Fire_Guide.md`).
- **Top-side "wire-art" routing adopted for camera appeal:** ULN flipped 180° (notch RIGHT) so IN faces the 595 and OUT faces the solenoid landing holes; rails spaced 2-2-2-2; 11-row chip gap.
- **The flip scrambles channel order.** Cut list recommended *nearest-IN* wiring (7 identical parallel jumpers, scramble absorbed in firmware `MAP`). **Daniel chose canonical order instead (Q0→IN1, Q1→IN2…)** — electrically identical, wired as a crossing fan of unique-length jumpers; MAP becomes sequential. As-built decision, applies to all 11 cells.
- Cell #1 dry-fit July 1 (photo on file); rails and soldering next, then the cold-continuity gate before the wire set is copied ×10.

## Phase 7 — Harness architecture (July 1, 2026)

- Problem: as originally drawn, every solenoid sent BOTH leads to the driver board = 168-wire harness (see: wire-mess photo).
- **Decision: plate-side +12V distribution.** Bare doubled-22AWG bus along each mounting wall, walls tied by a trunk, fed by ONE 18AWG wire from the board's +12V rail (which stays — COMs + reservoir live there). No ground to the plate; return is via the low-side wires.
- Result: **85-wire harness (84 grey low-side + 1 orange feed) instead of 168.**
- Disciplines adopted: **label landing holes, not wires** (84 identical black leads — position is identity; log `cell · OUT · key` at solder time); **cut each wire to length only at the moment it's landed.**

## Content thread (ongoing)

- Social strategy, content calendar, and per-video scripts (video 3 w/ EE guest, video 4 2×2 B-roll, solenoid-plate short) tracked alongside the build. The $0 gag in the bank: macOS Mouse Keys — "the robot refuses to touch the mouse."

## Still open (as of July 1, 2026)

- Wave 2 mouse approach: shortlist stands (animatronic hand on gantry / trackball spinner / 5-bar arm / holonomic rover) — no decision.
- FIRE reliability test on the mounted plate (pulse tuning at scale).
- Plunger spring rate / resting force (open question #5); keycap height clean measurement (#7).
- Cell #1: rails, solder, continuity gate, first fire from a soldered board (milestone).

---

## Folder cleanup record — July 1, 2026

Deleted after review (all recoverable from git commit `84a796c`): `Plate_Left/Right.stl` (superseded plate pair), card-cage plan + assembly SVG (abandoned architecture, summarized above), `Driver_Board_2Board_Layout.svg` (3-board chosen), 84-key CAD-phase docs (`Fusion_CAD_Build_Guide_84Key.md`, `Full_84Key_Split_Plate_Design_Brief.md`, `Join_Clarify.svg`, `Plate_Holes_Air75.dxf`, `Seam_Air75.dxf`), 2×2-phase docs (`Week3_2x2_Prototype_Plan.md`, `CAD_Design_Brief_2x2_Prototype.md`, `TestFitCell_v2.stl`), and junk (`.DS_Store`s, stale `.~lock` files). Kept by choice: all 2×2 STLs + DXF, all video/content docs, `Driver_Board_Wiring_Map.svg`, empty `docs/` stubs.

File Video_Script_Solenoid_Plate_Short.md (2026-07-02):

# Short-form script (Mark Rober style) — "I built a robot hand that types" (Part X)

**Platform:** Instagram Reels / X · **Format:** 9:16 vertical · **Length:** ~80s · **Audio:** VO over b-roll + face shots
**Voice:** curious, excited, talks-with-his-hands. Pose a problem, hit a snag, drop a big satisfying number, pay it off. Captions burned in (assume muted), cut every 1.5–3s.

---

## HOOK — 0:00–0:05  *(face shot, hold a single solenoid)*

- **B-roll:** You, close, grinning, holding one solenoid like it's a tiny treasure.
- **On-screen text:** `Why would I do this??`
- **VO:** "Okay, so I just spent 350 bucks building a robot whose entire job is to press keys on a keyboard. And no — I couldn't just use software. Stick with me, because this is way cooler than it sounds."

## SETUP — 0:05–0:16  *(pile / unboxing — TO SHOOT)*

- **B-roll:** Dump all 100 solenoids into frame, slow-mo. Pile fills the screen.
- **On-screen text:** `100 robotic fingers 🦾`
- **VO:** "Meet the star of the show: the solenoid. Think of it as a tiny robotic finger — give it electricity, and it punches. I needed one for every single key… so naturally, I bought a hundred of 'em."

## HOW IT WORKS — 0:16–0:29  *(firing motion diagram — slow it down)*

- **B-roll:** Screen-record of the firing cross-section, idle → energize → press. Punch the "thunk" SFX on contact.
- **On-screen text:** `magnet → SNAP → keystroke`
- **VO:** "And here's the genius part. Inside is a coil of wire. Power it up, it turns into a magnet and yanks this steel rod down like a mousetrap. A little rubber tip taps the key, a spring snaps it back — and boom. One perfect keystroke."

## THE PROBLEM — 0:29–0:42  *(CAD — HAVE)*

- **B-roll:** Fusion 360 — spin the plate, then exaggerate the tilt, show the flat-vs-tilted gap.
- **On-screen text:** `Problem: keyboards aren't flat 😬`
- **VO:** "But then I hit a wall. Keyboards aren't flat — yours is tilted about four degrees right now. So a flat plate of fingers? The front keys would never get touched. The fix: tilt the whole plate to match, so every finger has the exact same reach. Boom."

## ASSEMBLY — 0:42–0:55  *(mounting solenoids — TO SHOOT)*

- **B-roll:** Fast, satisfying cuts of screwing solenoids in, a row filling up. End on a punch-in of the last screw.
- **On-screen text:** `168 screws. send help.`
- **VO:** "Then came the *fun* part. And by fun, I mean mounting all 84 of these by hand. Two screws each — that's a hundred and sixty-eight tiny screws. My thumb may never recover."

## THE TEST — 0:55–1:08  *(testing the 84 — HAVE)*

- **B-roll:** Solenoids snapping on the bench, build to your most satisfying firing clip. Land the loaded plate.
- **On-screen text:** `will ALL 84 fire?? 👀`
- **VO:** "Moment of truth. These are dirt-cheap bulk parts, so some of 'em are basically guaranteed to be duds. So I tested every… single… one — to find 84 keepers." *(beat — let the best clip breathe)*

## PAYOFF + TEASE — 1:08–1:20  *(hero shot → face)*

- **B-roll:** Slow pan across the fully loaded plate. Cut to your face, satisfied.
- **On-screen text:** `Part X → making it type on command`
- **VO:** "And… there she is. A robotic hand that types. Next up, I wire all 84 to a brain so it can type literally anything I tell it to. Smash that follow — because this is about to get wild."

---

## Production notes (the Mark Rober touches)
- **Analogy first, jargon never:** "robotic finger," "mousetrap," "give it a brain" — never say "actuator" or "GPIO" out loud. The diagram carries the technical truth; the VO keeps it fun.
- **The problem→fix beat (0:29) is the heart of the style.** Don't cut it. The tilt reveal is your "ohhh, clever" moment — the thing the hater's reaction videos can't fake because you actually solved it.
- **Big-number spectacle:** let "168 screws" and "100 of 'em" land with a beat and a text pop. Rober always lets the absurd number breathe.
- **Sound design is half the video:** punch the solenoid "thunk" on the firing diagram and every test clip. That snap is your signature sound.
- **Two hook options:** (A) the $350 line above; (B) cold-open on the firing diagram looping + "There's no hand pressing this key. Watch." Test both, keep the higher-retention one.
- **Captions:** big, high-contrast, upper-third (dodge the IG UI). Burned in.
- **Loop it:** last frame (loaded plate) should rhyme with the opening pile so a replay feels seamless.

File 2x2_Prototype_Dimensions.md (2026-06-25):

# 2×2 Prototype — Master Dimensions

Quick-reference for the finished one-piece 2×2 prototype (`Prototype_2x2.stl`). All values in mm unless noted. Origin = center of the **S key** plunger hole. X = right, Y = toward keyboard back, Z = up. Plate bottom = Z 0, plate top = Z 4.

## Quick table (simplified names)

| Name | Value | What it is |
|---|---|---|
| `key_pitch` | 19.05 | key-to-key spacing, both axes |
| `stagger` | 4.76 | back row shifted left of front row |
| `tilt` | ~4.28° | plate tilt (back up); was 4°, moving the legs in shrank the leg span |
| `plate_thickness` | 4 | flat plate thickness |
| `plate_size` | 148 × 48 | plate length (Y) × width (X) — trimmed 5mm/end (was 158) |
| `plunger_hole` | Ø10 | plunger clearance hole (4 of them) |
| `screw_hole` | Ø3.3 | M3 clearance in walls (8 total), + Ø6×1 flat counterbore on the head/back face |
| `screw_spacing` | 15 | vertical gap between the 2 screw holes |
| `wall_offset` | 8 | hole center → wall mounting face |
| `wall_thickness` | 2.5 | mounting wall thickness — was 4, thinned off the BACK face for body slip-fit |
| `wall_height` | 28 | wall height above plate top (top at Z 32) |
| `lower_screw_z` | 7 above top (11 above bottom) | lower screw hole height |
| `upper_screw_z` | 22 above top (26 above bottom) | upper screw hole height |
| `front_leg` | 23.9 | front leg height |
| `back_leg` | 34.5 | back leg height (unchanged; tilt now ~4.28° after legs moved in) |
| `leg_gap` | 136 | inner gap between legs — was 146; legs moved in 5mm/side; still clears the 128.9 board |
| `overall_height` | 66.5 | bottom of back leg (Z −34.5) to wall top (Z 32) |

## Plunger holes (Ø10) — center positions (X, Y)

| Key | X | Y |
|---|---|---|
| S | 0 | 0 |
| D | 19.05 | 0 |
| W | −4.76 | 19.05 |
| E | 14.29 | 19.05 |

## Mounting walls

- **Front wall** (holds S, D): mounting face at Y 8, **2.5 thick → back face at Y 10.5** (~0.55 clear of the back body at Y 11.05), spans X −8…27, Z 4…32.
- **Back wall** (holds W, E): mounting face at Y 27.05, **2.5 thick → back face at Y 29.55**, spans X −13…23, Z 4…32.
- Screw holes (Ø3.3) per solenoid: centered on each plunger hole's X, at Z 11 and Z 26 (i.e. 7 and 22 above the plate top), 15 apart. **Each gets a Ø6 × 1 flat counterbore on the back/head face so the M3×3 flat head sits flush** (front-wall holes essential; back-wall optional).

## Legs (fused to plate, one piece)

- **Front leg:** Y −63.5…−57.5, height 23.9 (Z 0 → −23.9). (Moved in 5; was −68.5…−62.5.)
- **Back leg:** Y 78.5…84.5, height 34.5 (Z 0 → −34.5). (Moved in 5; was 83.5…89.5.)
- Inner gap (desk straddle) = 136. Leg spacing (center-to-center) = 142.
- Height difference 10.6 over 142 = ~4.28° tilt (heights unchanged; moving the legs in shrank the span).

## Solenoid (JF-0530B)

- Body 30 × 16 × 15. Plunger Ø6 × 58, 10 stroke.
- Mounting tab ~1 thick (re-measured; was ~1.5), **tapped M3**, 2 holes 15 apart, axis parallel to plunger.
- Lower mount hole → ball tip at rest = 15.
- Ball tip sits ~4 below the plate bottom at rest.
- **Screws: M3×3 FLAT-head** (flat-bottom, M3 thread; was M3×6 cap), seated in the Ø6×1 flat counterbore so the head is flush.

## Keyboard / assembly (Nuphy Air75 V3, feet retracted)

- Keyboard depth straddled = 128.9.
- S key = 54 from the keyboard front edge.
- Keycap height above desk: **S = 23**, **W = 24.5** (→ ~4.5° measured key tilt).
- Resulting ball-to-keycap gap at rest: **~1.5 over S, ~1.3 over W.**
- Leg clearance: ~8.5 in front of and behind the keyboard.

## Notes

- These are the validated values from the printed test-fit cell + the measured solenoid and keyboard. `lower_hole_z` was corrected 3 → 7 (the +4mm fix). `plunger_hole` widened 7 → 10. Screws confirmed M3, not M2.5.
- **June 2026 redesign (from the in-hand 2×2):** wall 4 → 2.5 (body slip-fit), M3×6 cap → M3×3 flat-head + Ø6×1 flat counterbore on the head face, plate 158 → 148 (5/end), legs moved in 5 (straddle 146 → 136, tilt ~4.0 → 4.28°). Assemble bottom row first, then top. No gussets (firing recoil is in-plane). Rationale in CLAUDE.md → "2×2 redesign."
- Open: confirm the M3×3 flat-head bites the ~1mm tab and holds (tip ~0.5 past the tab); FIRE test pending. Leg heights assume ball-4mm-below-plate and 23/24.5 keycap heights — shim-tunable if reality differs.

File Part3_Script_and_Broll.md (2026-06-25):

# Physical AI Agent — Part 3: Shooting Script

**Format:** Vertical 9:16 · ~60 sec · Instagram Reel / X
**Style:** Documentary build-log — honest, process-forward
**Structure:** Cold open on the payoff (typing **FREED**), rewind through the build, tease next week
**Payoff word:** FREED — keys E, R (top row) + D, F (bottom row); fires all four solenoids, E twice
**Gear:** phone + tripod (overhead), clip-on lavalier mic, CapCut

---

## 1. Script + shots (beat by beat)

| # | Time | Voiceover | Caption | What to shoot / B-roll |
|---|---|---|---|---|
| **Hook** | 0–3s | "This machine just typed the word FREED — completely by itself." | FREED | Macro of solenoids hammering + screen capture of F‑R‑E‑E‑D landing in TextEdit. *(Retention trick: cut away before the word finishes; complete it at the end.)* |
| **Turn** | 3–9s | "This is part 3 of building my physical AI agent. Last week I got the electronics firing a solenoid on the breadboard. This week I printed the housing that holds them over the keys — and it fought me." | PART 3 · this week: the housing | Quick clip of last week's breadboard solenoid click → cut to the 3D printer starting a print. |
| **Beat 1** | 9–22s | "First, a little holder for one solenoid, just to nail the screw-hole spacing. The screws I bought off the spec were too loose — they'd thread on, then spin right back out — so I sized up to a bigger screw. Once that one fit solid, I printed the 2×2 prototype: four solenoids, two rows." | screws too loose → sized up | **CAD: test-fit cell (slow orbit).** Printer peeling the part. Macro: screw threading on, then spinning loose / falling out. Bigger screw biting + holding. |
| **Beat 2** | 22–38s | "But the first 2×2 missed something — the screw heads. They stuck out and jammed into the solenoid sitting behind them, and the wall between the rows was too thick to fit in the gap. That row couldn't even bolt down." | screw heads jammed | **CAD: first 2×2 (slow orbit) — punch in on the cap-screw head hitting the body behind it.** Physical: the failed 2×2, head fouling the neighbor; wall too fat for the gap. |
| **Beat 3** | 38–52s | "So I redesigned it: a counterbore at each hole — a flat-bottomed pocket the head sinks into — shorter, flat-topped screws so they sit flush, and a thinner wall to give the solenoids room. And that's how it typed FREED." | counterbore = flush | **CAD: redesigned 2×2 (slow orbit) — close-up on the counterbore pockets; v1-vs-v2 side-by-side.** Physical: flush heads (finger drags across), 4 solenoids seated, block lowering onto E/R/D/F → return to the firing + FREED on screen. |
| **Close** | 52–60s | "Next week, I scale this up — from four keys to all 84. Four down, eighty to go." | NEXT: 84 keys · 4 down, 80 to go | Slow push on the full Nuphy keyboard; optional 1-sec flash of all three CAD designs in sequence (the evolution). |

> Runtime note: VO is ~160 words — tight for 60s. If it feels rushed, trim Beat 1 (the screw line) or shorten the Turn.

---

## 2. CAD design-iteration montage ("every design")

Record each model in Fusion 360 and play them **in the order they happened** so the montage *is* the iteration story — the viewer watches the design evolve:

1. **Test-fit cell** (`TestFitCell.stl`) — single-solenoid holder → plays at **Beat 1**.
2. **First 2×2** (the failed design — 4 mm wall, M3×6 cap screws) → plays at **Beat 2**, punched in on the screw head colliding with the body behind it. *(If you didn't keep this CAD state, roll the Fusion timeline back to it, or just show the physical failed print.)*
3. **Redesigned 2×2** (`Prototype_2x2.stl` — 2.5 mm wall, counterbore, M3×3 flat-top) → plays at **Beat 3**, close-up on the counterbore pockets.

How to capture:

- Screen-record with the model **slowly orbiting** (drag the ViewCube, or set up an orbit animation). 3–5 sec per model is plenty.
- Shoot one **v1-vs-v2 side-by-side** (or a quick cross-dissolve) so the counterbore + thinner wall pop — that's the whole redesign in one shot.
- Hero shot: a tight **punch-in on a single counterbore pocket** with a screw dropping in flush.
- Optional: a 1-sec **"all three in a row"** flash at the Close to show the evolution.

---

## 3. Master B-roll checklist

**CAD (Fusion 360 screen-records)**

- [ ] Test-fit cell — slow orbit
- [ ] First 2×2 — slow orbit + punch-in on screw-head collision
- [ ] Redesigned 2×2 — slow orbit + counterbore close-up
- [ ] v1 vs v2 side-by-side
- [ ] (Optional) all-three evolution flash

**Printing**

- [ ] Printer starting a print (nozzle moving)
- [ ] Test-fit cell peeling off the bed
- [ ] 2×2 building up (time-lapse)

**Solenoid + assembly**

- [ ] Macro of the JF-0530B solenoid in hand (plunger, ball tip)
- [ ] Seating a solenoid into the holder / wall
- [ ] Loose screw threading on, then spinning out / falling
- [ ] Bigger screw biting + holding
- [ ] Flush counterbored heads (finger drag across)
- [ ] 4 solenoids mounted in the 2×2
- [ ] Block lowering onto the keyboard (E / R / D / F)

**Payoff**

- [ ] Wiring to the breadboard / Arduino
- [ ] Solenoids firing in sequence — **high frame rate for slo-mo**
- [ ] Screen capture: FREED appearing letter by letter in TextEdit
- [ ] Hand-vs-rig on the same four keys (side-by-side)
- [ ] Slow push on the full Nuphy keyboard (for the Close)

---

## 4. Captions / on-screen text (muted viewing)

FREED → PART 3 → screws too loose → 2×2 prototype → screw heads jammed → counterbore = flush → NEXT: 84 keys

---

## 5. Production notes

- **Vertical 9:16, 1080p.** Phone on the tripod overhead for bench/process shots; get **macro** on the solenoid and the screen.
- **Audio is the star:** capture clean **solenoid clack** separately, and record VO with the lavalier. The clack sells it on muted feeds.
- **Slo-mo** the firing (highest frame rate your phone allows). Lock manual exposure so lighting doesn't shift between clips.
- **Pace:** ~6 beats, brisk cuts, light music bed under VO. Cut on the clacks where you can.
- **Capture the real first successful run** — that's the honest beat — but shoot a few takes as backup.
- **Diction:** the script says "flat-topped screws" on purpose. "Flat-head" formally means a *countersunk, conical* head (pairs with a countersink, not a counterbore). Yours is a flat-bottomed cap-style head in a counterbore — so "flat-topped / low-profile screws" stays accurate if a maker is watching. "Counterbore" is the correct term for the pocket.

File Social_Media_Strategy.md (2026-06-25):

# Physical AI Agent — Building in Public Strategy
**Your social media playbook. 12 weeks. 4 platforms. Starting from zero.**

---

## Why This Project is Inherently Viral

Before any strategy: you are building something that almost no one has seen before. A robot with 84 solenoids that physically presses keys on a real keyboard, controlled by AI. This is not a software demo. You can film it. You can hear it. You can smell the solder. That sensory reality is your biggest competitive advantage over every other "AI project" on the internet right now.

The hook writes itself: *"I'm building a robot so AI can type on a real keyboard."*

People will immediately ask: "Why not just use software?" That question IS your content engine. You answer it over 12 weeks.

---

## Brand Positioning

**Your handle:** Pick one consistent name across all platforms. Suggestions: `@danielbuildsthings`, `@physicalai`, `@solenoidseason` (fun), or just `@danielbaek` (personal brand). Go personal brand — it ages better than project-specific names.

**Your one-liner (use in every bio):**
> "Building a robot that physically types on a keyboard. 84 solenoids. 12 weeks. $1,366 budget. Follow the build."

**Your content identity:** *Educational + hype.* You're the person who explains why something is genuinely hard, makes the viewer feel smart for understanding it, then delivers a satisfying payoff. Think early Mark Rober energy — not just "look at this cool thing" but "here's why this is actually a fascinating engineering problem."

**The "why" you return to constantly:**
Software AI agents use APIs and virtual interfaces. A physical AI agent can use *any* computer, any interface, anything a human can use — because it's using the same physical input devices. That framing is compelling to both the AI community and the maker community. Use it.

---

## Content Pillars

Every post you make should fit into one of these five buckets:

### 1. The Milestone Moment
The first solenoid fires. The first letter types. The first word. The first sentence. The first time the AI completes a task end-to-end. These are your biggest posts. Film them properly. Post them immediately. Add a number: "Day 14: First keystroke."

### 2. The Explainer
"Why does this need 84 solenoids?" "How does a solenoid even work?" "Why is 19mm pitch important?" Short, fast, educational. These get saved and shared. They build authority.

### 3. The Struggle
Wrong parts ordered. Solenoid fires sideways. CAD doesn't fit. PSU current math is wrong. These are your most *relatable* posts and often outperform the wins. Be honest. The M2 vs M2.5 screw discovery? That's a video. "I ordered 168 wrong screws" is a great hook.

### 4. The Unboxing / Arrival
Parts arriving from AliExpress. The 100-solenoid haul. The prototype kit. These are satisfying and cheap to film — just set up your phone pointed at your desk. The solenoids clicking in the box will sound incredible.

### 5. The Big Question
Polls, debates, design choices. "Should the side rails run front-to-back or left-to-right?" "What should the robot type first?" Community involvement creates investment. They'll follow to see if their answer wins.

---

## Platform Strategy

### TikTok & Instagram Reels & YouTube Shorts
*(Same video, posted on all three)*

**Format:** Vertical 9:16. 30–60 seconds. Captions ON (always).
**Structure:**
- **0–2 sec:** Visual hook. Show the most impressive thing first — solenoid matrix firing, robot typing, parts spread across a table. NO intro, NO "hey guys."
- **2–10 sec:** Stakes. Why should anyone care? One sentence.
- **10–45 sec:** The story/explanation/struggle.
- **45–60 sec:** Payoff or cliffhanger. Either the satisfying result OR "next video I'll find out if this works."

**Posting cadence:** 2x per week. Tuesday and Friday are your best days to post. Aim for 6–9pm local time.

**Audio:** Use trending sounds under build content (check TikTok's trending audio weekly). For milestone moments, let the real sound lead — 84 solenoids firing is better than any trending audio.

**Caption formula:**
```
[Hook restatement in text]
[1-2 lines of context]
.
.
.
[3-5 relevant hashtags]
```
Hashtags to rotate: `#buildinpublic` `#robotics` `#diy` `#engineering` `#aiagent` `#maker` `#arduino` `#solenoid` `#buildingthefuture`

---

### X / Twitter

**Format:** Mix of text threads, short clips (under 2:20), and images.

**Thread template for weekly updates:**
```
Tweet 1: The hook. One surprising sentence. A number.
  → "Week 3: I printed a 4×4 test plate and fired the first solenoid. Here's what happened."

Tweet 2-4: The story. Short sentences. One idea per tweet. Images/clips attached.

Tweet 5: The ask or forward look.
  → "Week 4 I'm wiring all 84. If I burn one out, I deserve it."
```

**Posting cadence:** 3–4x per week. At least one thread per build week. Short clips or photos on the other days.

**Accounts to engage with authentically:**
- @sama, @karpathy, @levelsio (indie builder energy)
- Maker/robotics accounts: @hackster_io, @adafruit, @sparkfun
- Engage *before* you post — reply to their content, build presence, then post your own

**Pin tweet:** Once you have your launch video up, pin a tweet with the concept video + one-liner. This is your landing page for anyone who clicks your profile.

---

## The Audio Advantage

This is your secret weapon and almost no one talks about it: **the sound of your robot will drive engagement.**

84 solenoids firing in sequence sounds like a typewriter from the future. A single keystroke sounds like a satisfying mechanical click. When your robot types its first word, the audio is shareable on its own.

**Tactical use:**
- Never mute the real sound in build videos unless you need to
- For at least one video, strip all music and let the solenoid clicks be the only audio
- The "ASMR robot typing" angle is a real sub-niche — consider one dedicated clip
- When the full matrix fires, record it with your phone mic AND a directional mic if you have one

---

## Thumbnail & Cover Frame Formula

For every video, your first frame (which becomes your thumbnail/cover) should show:

1. Something physically surprising (solenoids firing, wires everywhere, keyboard with metal matrix above it)
2. A number (Day X, Week X, $X budget, X solenoids)
3. Your face if possible — human face in thumbnail increases CTR on YouTube especially

Avoid: blank desks, circuit boards without context, text-only thumbnails at the start.

---

## The 12-Week Arc

Your build has a narrative structure that maps perfectly to a content series. Here's how to frame each phase:

| Weeks | Build Phase | Content Theme |
|---|---|---|
| 1–2 | Parts arriving, first PCB test | "Is this even possible?" |
| 3–4 | First solenoid fires, 4×4 test plate | "It's alive." |
| 5–6 | Full 84-key matrix assembly | "The grind" |
| 7–8 | Vision system (webcam + OCR) | "Now it can see" |
| 9–10 | Wave 2: XY gantry for mouse | "Now it can move" |
| 11 | AI integration, first full task | "First words" |
| 12 | Endurance test, final demo | "The payoff" |

Frame this explicitly for your audience: "I'm doing this in 12 weeks. Follow the whole build." People love a timeline. It creates urgency and investment.

---

## Viral Moment Checklist

These are the specific moments in your build that have the highest viral potential. Be ready to film them properly:

- [ ] Unboxing all 100 solenoids (satisfying volume, sound, weight)
- [ ] First single solenoid fires on bench test
- [ ] First letter typed by solenoid on real keyboard
- [ ] First word typed (especially if it's something funny — make the first word "hello" or "hi mom")
- [ ] First time the AI decides what to type
- [ ] Full 84-key matrix firing in sequence (the visual and audio of this alone is a viral clip)
- [ ] A solenoid failing / firing wrong / breaking something
- [ ] The robot completing its first real task (opening an app, sending a message)
- [ ] Speed test: how fast can it type? Compare to human WPM.
- [ ] The endurance test (2 hours of continuous use)

**For each of these moments:** have your phone on a tripod filming before you start. Don't try to capture it mid-attempt. Set up first, attempt second.

---

## What Viral Build Creators Do Differently

The accounts that broke out — Stuff Made Here, Michael Reeves, Simone Giertz, William Osman — share these traits:

**They show the failure honestly.** The robot types the wrong key. The solenoid misfires. The CAD doesn't fit. Showing failure is not weakness — it's proof you're actually building something hard, and it makes the eventual success feel earned.

**They are specific.** Not "I built a robot." "I built a robot with 84 solenoids, each one wired to a different key, that fires in 20 milliseconds, controlled by an AI running on my laptop." Specificity = credibility = shareability.

**They talk to the audience like they're smart.** Don't oversimplify. Say "solenoid" not "magnet thing." Explain what a 5N force means. People will google the rest — and that means they're invested.

**They have a recurring bit or catchphrase.** Simone had "shitty robots." Reeves had "I built a robot that [does something terrible]." For you: every video ends with the current count. "84 keys down. 0 typed. Next week that changes." Or a consistent frame: "Week X of building the world's most unnecessary keyboard."

**They post consistently.** Viral moments need an audience to land. The audience comes from posting consistently even when nothing viral is happening. A "Week 3: Everything is still in boxes" video still builds your following.

---

## Starting From Zero: The First 30 Days

The hardest part is the first 30 days with no audience. Here's the play:

**Week 1:** Post the concept video. One 60-second video: what you're building, why, what the finished thing will do. Don't have footage yet? Film yourself at your desk explaining it. Show the spreadsheet. Show the parts you've ordered. The ambition alone is compelling.

**Week 2:** Post an explainer. "Why does an AI need to physically type?" This is the question everyone will have. Answer it. This video will get shared by AI-curious people who aren't even in the maker community.

**Week 3:** Post the first unboxing. Solenoids arriving. Film the entire unbox in one continuous shot. The pile of 100 solenoids on your desk is a striking image.

**Throughout:** Comment on 10–20 posts per day from accounts in your space on X. Not spam replies — actual thoughts. This is how you get initial followers before you have a big post.

---

## What NOT to Do

- Don't wait until it's finished to start posting. The journey IS the content.
- Don't use copyrighted music on TikTok/Reels (use the in-app music library or royalty-free sources like Uppbeat or Pixabay)
- Don't post without captions. 85% of videos on TikTok/Reels are watched on mute.
- Don't explain the joke. If something is funny or satisfying, let it land. Cut before it gets boring.
- Don't post the same video on the same day to all platforms. Stagger by 1–2 days. The algorithm rewards unique content.
- Don't obsess over production value early. Your phone + decent light + interesting subject matter beats professional gear + boring subject. Get the tripod and the ring light from Amazon ($30 total). That's enough.

---

## Gear You Need (Minimal)

You already have the C920 webcam for vision. For content:

- **Phone tripod:** $15–20 on Amazon. Essential.
- **Ring light or clip LED:** $20–25. Huge difference vs overhead fluorescent.
- **Lavalier mic (optional):** $25–35. Better audio for explainer-style talking-head clips.
- **CapCut (free):** Best free editor for TikTok/Reels. Auto-captions, trending effects, fast export.

Total gear investment: ~$60. The content quality comes from the subject matter, not the equipment.

---

*Last updated: May 2026. Maintained by Claude as your social media manager.*

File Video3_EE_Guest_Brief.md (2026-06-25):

# Video 3 — Guest Brief: [Friend's name]

*One-pager so you know your role before we film. — Daniel*

## The hook: Aggie builds it, Longhorn keeps it from burning down

I (Texas A&M) spent three prints and two wrong screw sizes getting the mechanical mount right. You (UT Austin) are the electrical engineer I'm trusting to make sure the circuit doesn't release the magic smoke the first time 12V hits four coils. Best friends since high school, opposite sides of the Lone Star rivalry, finally forced to work on the same machine. That's the episode.

**Cold-open idea:** *"I go to A&M. My best friend goes to UT. We agree on almost nothing — but he's the one person I trust to keep my $1,400 build from catching fire."*

## Your role

You're the **electronics guy** for the series. In Video 3 you're not building from scratch — the LED→Solenoid prototype already drives them. Your job:

- Explain the driver circuit the audience already saw, so they understand *why* it works.
- Sanity-check it before we put 12V through four coils.
- Look ahead to the real problem: scaling 4 channels to 84.

One rule: you can be there for the first word, but **I hit the key.** It's an Aggie milestone.

## The segment you own

Right after the mechanical half ("the mount finally fits — now I have to make these things actually fire"), it's yours. Walk through how a 5V Arduino pin ends up slamming a 12V solenoid into a keycap.

## Your talking points (all specific to this build)

- **The flyback diode — your headline.** A solenoid is an inductor; cut the current and the collapsing field kicks back a voltage spike that fries the switching transistor. A diode across the coil (banded end toward +12V) clamps it. Great line: *"This 3-cent diode is the only thing between an Aggie's wiring and a cloud of smoke."* Optional stunt: fry a bare MOSFET without one on camera, then add the diode.
- **Why you can't drive it off the Arduino.** A pin sources ~20mA; the JF-0530B wants ~300mA at 12V. So each channel gets a logic-level N-channel MOSFET as a low-side switch (solenoid + to 12V, solenoid − to drain, source to ground, gate to the Arduino).
- **Common ground.** Arduino GND tied to PSU GND, or the gate has no reference and nothing switches. The classic beginner killer.
- **Gate resistor + pulldown.** ~150Ω in series, 10k gate-to-ground, so the coils don't chatter or fire on power-up while the Arduino boots.
- **Power budget.** Four coils now, but the 480W / 40A PSU is sized for many firing at once at ~300mA each — and explains why solenoids never run off the Arduino's regulator.
- **PWM holding trick.** Full power to pull, lower duty cycle to hold → less heat. Directly addresses our endurance/thermal worry.
- **4 → 84.** Shift registers (74HC595) or driver arrays instead of burning 84 Arduino pins. This plants the seed for future episodes.

## Rivalry beats you can riff on (keep it friendly)

- Maroon wire vs. burnt-orange wire. Each refuses to touch the other's color.
- *"An Aggie built a frame that actually works. I'm as surprised as you are."* → I fire back with Aggie pride.
- First word: classic is "HELLO WORLD," but a rivalry pick ("GIG EM" vs "HOOK EM," or "WHOOP") makes the other one groan on camera. Pick the word for the reaction.
- Gig 'em vs. Hook 'em at the sign-off.

## On camera, please

- Tie every point to a part in your hand or something on the bench — no whiteboard lectures.
- Keep takes tight; we'll cut around the tangents.
- The banter is seasoning. The engineering is the meal.

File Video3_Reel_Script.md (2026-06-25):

# Video 3 — Instagram Reel Script (~90 sec)

**Format:** Vertical 9:16 · fast cuts · captions burned in · hook text on frame 1
**Style:** Hybrid — VO + the diode explainer are word-for-word; [BANTER] lines are prompts to riff on
**Cast:** You (Texas A&M) · [Friend] (UT Austin, EE)
**VO target:** ~180 spoken words to land at 90s — don't add more

---

### 0:00–0:04 · HOOK
**VISUAL:** Hard punch-in on the keyboard rig. Friend leans into frame in burnt orange, you in maroon.
**VO (you):** "My best friend goes to UT. I go to A&M. Today we find out whose engineering actually works."
**TEXT (frame 1):** Aggie 🤝 Longhorn build a typing robot

### 0:04–0:22 · THE SAGA SO FAR (fast montage)
**VISUAL:** Rapid cuts of the prints.
**VO (you):** "Recap. First mount — the wall was too short. But the screw holes lined up perfect. So I reprinted it taller, and it fit."
**TEXT (as cuts):** Wall too short ❌ → Screw holes ✅ → Reprint, taller ✅
**VISUAL:** Close-up — an M2.5 screw spinning loose and falling out, then an M3 threading in tight.
**VO (you):** "Then the screws I ordered didn't fit. The listing lied. M2.5 just spins out — turns out I needed M3."
**TEXT:** M2.5 spins loose ❌ → M3 bites ✅

### 0:22–0:30 · THE 2×2 PRINTS
**VISUAL:** Printer finishing the 2×2; you pull it off the bed, snap in the 4 solenoids.
**VO (you):** "New 2×2 prototype comes off the printer. Four solenoids from the last build drop right in."
**TEXT:** 2×2 prototype ✅

### 0:30–0:55 · ENTER THE LONGHORN (electronics)
**VISUAL:** Friend steps into frame, picks up the wiring.
**VO (you):** "But I don't trust myself with the electronics. So I called in a real electrical engineer. From UT. I know, I know."
**TEXT:** Calling in backup… from UT 🤘😒
**[BANTER — friend]:** something like *"Someone's gotta keep the Aggie wiring from catching fire."*
**VISUAL:** Friend points to the little diode across a solenoid.
**VO (friend) — word-for-word:** "See this diode? A solenoid is just an inductor. Cut the power and it kicks back a voltage spike that'll fry your transistor. This clamps it — no magic smoke."
**TEXT:** Flyback diode = no magic smoke
**[BANTER — you]:** fire back with Aggie pride — *"The frame, though? Flawless."*

### 0:55–1:08 · WIRE UP + TENSION
**VISUAL:** Plug into the 12V supply. Arduino ready. Hands clear of the keyboard.
**VO (you):** "Power supply on. Twelve volts, four solenoids, one keyboard. Moment of truth."
**TEXT:** First word incoming…

### 1:08–1:22 · PAYOFF — THE FIRST WORD
**VISUAL:** Tight on the screen. Solenoids punch the keys — *clack clack clack*. Letters appear.
**SFX:** Loud mechanical clacks, then silence.
**VO (you), quiet → hyped:** "It typed. It actually typed."
**TEXT:** big reveal of the word as it lands
**[BANTER]:** reaction depends on the word (see note) — if it spells **GIG EM**, the Longhorn groans on camera.

### 1:22–1:30 · SIGN-OFF / CTA
**VISUAL:** Both of you in frame, rivalry energy.
**VO (you):** "Aggie built it. Longhorn wired it. Follow to watch us make it type all 84 keys."
**[BANTER]:** Gig 'em vs. Hook 'em.
**TEXT:** Ep 4: all 84 keys 👀 · Follow

---

## Production notes

- **First word — pick for the reaction.** Punchy option: **`GIG EM`** (Aggie flex, Longhorn groans — best reel payoff). Classic option: **`HELLO WORLD`** (the tech-audience trope; cleaner, less rivalry juice). Recommend GIG EM for a 90s reel.
- **Hook is everything.** Frame 1 needs the rivalry text on screen before anyone speaks — that's your scroll-stopper.
- **B-roll to grab while filming:** screw spinning loose, M3 threading in, print peeling off the bed, solenoids snapping into the 2×2, the diode close-up, the keys getting punched, the word appearing.
- **Audio:** upbeat build track that drops out right before the first-word clacks, then hits on the reveal. A trending sound works if it has a clean beat drop at ~1:08.
- **Caption idea:** "An Aggie and a Longhorn tried to build a robot that types. Week 3. 🤖⌨️ #engineering #3dprinting #arduino #txst… er, #gigem #hookem #robotics #diy #makersgonnamake"

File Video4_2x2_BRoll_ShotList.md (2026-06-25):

# Video 4 — B-Roll Shot List (2×2 First Keystroke)

**Video:** "Day [X]: The first key press" — updated for the **2×2** prototype (front S/D, back W/E).
**Why 2×2 not 4×4:** it forces a two-row, *tilted (4°)*, *staggered (4.76mm)* mount — the two hardest parts of the whole build. That's your story.
**Golden rule:** film the success shot FIRST, multiple angles, before anything can break. Everything else is recoverable; the first clean keystroke is not.

---

## Phase 1 — CAD / Design (you're here now)
- [ ] **Screen recording: the parametric model rotating** in Fusion 360 — show the plate, the two mounting walls, the plunger holes.
- [ ] **Screen recording: change a parameter live** (e.g. `tilt_angle` or `pitch_x`) and let the whole model update. This is the "wow, it's parametric" beat.
- [ ] **Close-up of the tilt** — orbit to a side view so the 4° angle and the back-row-taller geometry is obvious.
- [ ] **Screen recording: the stagger** — top view showing the back row (W/E) offset left of the front row (S/D).
- [ ] **You at the keyboard, calipers in hand**, measuring key pitch (19.05mm) — establishes that this is measured, not guessed.
- [ ] **Hand on mouse / face lit by monitor** — a few seconds of "designing" ambiance for cutaways.

## Phase 2 — The Test-Fit Cell (the smart-engineer beat)
- [ ] **The single test-fit cell coming off the print bed** (one hole + one wall) — this is your "measure twice" move; it's relatable and makes you look careful.
- [ ] **Dropping one solenoid into the test cell** to check `wall_offset` — does it sit flush?
- [ ] **Close-up: caliper checking the plunger-to-key gap** on the test cell.
- [ ] *(Optional honesty beat)* if the wall_offset is wrong on the first cell — **film the reprint**. Failure footage makes the success earned.

## Phase 3 — Printing the 2×2 Plate
- [ ] **Time-lapse of the full 2×2 plate printing** (phone on tripod, locked off, shoot the whole print).
- [ ] **First layer going down** — close, low angle across the bed. Always a good clip.
- [ ] **Peeling the finished plate off the bed** — satisfying, tactile.
- [ ] **The plate + mounting walls held up in your hand**, turning it to show the holes and the angle.

## Phase 4 — Mounting & Assembly
- [ ] **Fast-cut / time-lapse of mounting the 4 solenoids** to the walls (M2.5 screws, side-face holes).
- [ ] **Macro: capping a plunger with silicone tubing** — tiny, detailed, very watchable.
- [ ] **Macro: driving an M2.5 screw** into the wall (the screw you re-ordered — callback to the "wrong screws" video).
- [ ] **The plate lowering onto the keyboard**, over W/E/S/D — overhead.
- [ ] **Shimming the plate to the 1–2mm gap** — caliper or feeler check between plunger tip and keycap.
- [ ] **Side-on hero of the finished rig**: 4 solenoids standing on their tilted walls over the keyboard. Hold this — it's your thumbnail candidate.

## Phase 5 — THE MONEY SHOTS (film these the most)
- [ ] **Solenoid fires → letter appears on screen.** Get it from 3+ angles: (1) macro on the plunger hitting the key, (2) the laptop screen, (3) a wide of rig + screen together.
- [ ] **Slow-motion of one plunger firing and striking the keycap** — highest frame rate your phone allows.
- [ ] **Screen close-up as the letters land** — the 2×2 gives you W, E, S, D. Fire them to spell a word ("**WEDS**" / "**SEW**" / "**DEW**") instead of random order; spelling something reads as success.
- [ ] **All four firing in sequence** — a little click-wave, clean audio, no music.
- [ ] **Macro from directly above** a key, plunger entering frame and pressing down.

## Phase 6 — Reaction & Wrap
- [ ] **Your genuine face reaction** to the first clean keystroke (don't fake it — keep the camera rolling during the real attempt).
- [ ] **Talking-head to camera** for the "one keystroke, but the concept works — scale by 21x" line.
- [ ] **Preview shot for next week**: the empty/future 84-key plate, or you holding the keyboard and gesturing at all the keys still to cover.

## Texture / cutaway B-roll (grab whenever, fills edit gaps)
- [ ] Desk/bench wide establishing shot.
- [ ] Pile of spare solenoids.
- [ ] The spreadsheet or CAD brief on screen (1–2 sec scope flash).
- [ ] Hands working — screwdriver, calipers, tweezers — shallow depth of field.
- [ ] The keyboard alone, clean, before the rig goes on (the "before").

---

### Audio reminders
- Leave the solenoid **click clean** — no music under the fire shots.
- Capture **room-tone / print-bed hum** for 30 sec for the edit.
- The print peel, the screw driving, the click — all natural-sound moments. Don't talk over them.

### Edit notes (carried from your master rules)
- **Open on the success** in the first 3 seconds, then walk back to CAD → print → mount.
- Add a counter graphic: **"Keystrokes: 1"** then **"4"**.
- Slow-mo is mandatory on the keystroke.
- Update the story beat: it's a **2×2 that exercises tilt + stagger**, not a 4×4 — say that, it's the more impressive version.

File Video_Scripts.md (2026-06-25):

# Video Scripts — Physical AI Agent Build Series
**5 scripts for videos 1–5. Each includes: hook, script, shot list, and edit notes.**

---

## VIDEO 1: The Launch / Concept Video
**Title:** "I'm building a robot that physically types on a keyboard"
**Platform:** All 4 (TikTok, Reels, Shorts, X)
**Length:** 45–60 seconds
**When to post:** NOW / Week 1, before parts even arrive

---

### Script

**[HOOK — 0:00–0:03]**
*On camera, holding up the Nuphy Air75 keyboard*

> "This keyboard is about to have 84 tiny robots sitting on top of it — one for every single key."

**[CONTEXT — 0:03–0:12]**
*Cut to: diagram or phone sketch of the concept. Or just talk to camera.*

> "I'm building a physical AI agent. Not software — an actual robot that presses real keys on a real keyboard. 84 solenoids. Individually wired. It'll be able to type anything the AI tells it to."

**[THE QUESTION — 0:12–0:22]**
*Back to face, slightly leaning in*

> "Yeah, I know — why not just use software? Here's the thing: software AI agents only work with apps that have APIs. A physical agent can use *any* computer. Anything a human can use. Because it's using the same hands."

**[STAKES / TIMELINE — 0:22–0:35]**
*Show the parts spreadsheet briefly, or a printed list. Casual.*

> "I've got 12 weeks and a $1,366 budget. Parts are ordered. The math says I need to fire each solenoid in about 20 milliseconds or the typing will sound like a drunk person. There's a lot that can go wrong."

**[CTA — 0:35–0:45]**
*Smile, direct to camera*

> "I'm posting every week. Week 3 I'll fire the first solenoid. Week 12 the robot types its first real sentence. Follow along — this is either going to be incredible or a very expensive pile of magnets."

---

### Shot List
- [ ] You on camera, holding keyboard (phone on tripod, eye level)
- [ ] Close-up of keyboard keys (overhead or side angle)
- [ ] Screen recording or quick sketch of the concept layout (84 solenoids above keys)
- [ ] Quick flash of the spreadsheet or parts list (just 1–2 seconds)
- [ ] Outro face shot — casual, confident

### Edit Notes
- Cut snappy. No shot should linger more than 3 seconds in the middle section.
- Captions on every line (use CapCut auto-caption, clean up errors)
- Add a subtle mechanical/typing sound effect under the "84 solenoids" line
- B-roll idea: timelapse of the spreadsheet scrolling (shows scope/seriousness)
- Color grade: slightly warm. You're in a workshop, not a corporate office.
- End card: "Week 2 coming [day]" with a preview frame

---

---

## VIDEO 2: The Explainer
**Title:** "Why does AI need to physically type?"
**Platform:** All 4
**Length:** 45–55 seconds
**When to post:** Week 1–2

---

### Script

**[HOOK — 0:00–0:03]**
*Direct to camera, slightly skeptical face*

> "Everyone's first question when I tell them this project: 'Why not just use software?'"

**[ANSWER — 0:03–0:25]**
*Cut between face and quick diagram/whiteboard sketch*

> "Software AI agents — like the ones you use in ChatGPT or Cursor — only work with apps that have an API. They need the software to cooperate.

> A physical agent doesn't need permission. It sees the screen through a camera, decides what to click or type, and just... does it. On *any* app. A hospital's 30-year-old software with no API. A game that blocks automation. A web page that breaks every bot.

> It uses the same interface a human uses — a keyboard and a mouse."

**[THE TWIST — 0:25–0:38]**
*Lean in slightly, slower pace*

> "That's actually why this is hard. Software is perfect. My robot has to deal with physical reality — tolerance errors, solenoid timing, OCR misreads. But that's also what makes it interesting."

**[CTA — 0:38–0:50]**

> "I'm 12 weeks into building one from scratch. Come back Friday — the parts just arrived."

---

### Shot List
- [ ] Face shot, slightly skeptical expression for hook
- [ ] Whiteboard or iPad sketch: "Software AI" with locked door vs "Physical AI" with real keyboard
- [ ] Screen recording: ChatGPT or Cursor UI (just the concept, no need for demo)
- [ ] Close-up of keyboard + your hand pressing a key naturally
- [ ] Face shot for closer/CTA

### Edit Notes
- The whiteboard sketch can be hand-drawn on paper and filmed overhead — don't overthink it
- This video should feel slightly more "educational YouTube" than the others — slightly slower pace than Video 1
- Text overlay on "any app" line: flash 3 icons (random apps) in quick succession
- Save-worthy content: people will share this explanation to answer "why" on your behalf. Make the explanation genuinely clear.

---

---

## VIDEO 3: The Unboxing
**Title:** "100 solenoids just arrived from China"
**Platform:** All 4
**Length:** 30–45 seconds
**When to post:** Week 2–3, day parts arrive

---

### Script

**[HOOK — 0:00–0:02]**
*Film the box arriving. If you can't film the delivery, film yourself cutting it open.*

> *(No talking — just the sound of tape cutting)*

**[THE REVEAL — 0:02–0:10]**
*Pull out the solenoids. One handful. Show quantity.*

> "One hundred solenoids. Each one wired to a different key on a keyboard. They need to fire in about 20 milliseconds each."

**[CLOSE-UP — 0:10–0:20]**
*Hold one up, click it manually with your finger*

> "Each one is basically a tiny electromagnet. When current hits it — [demonstrate firing with battery/hand] — the plunger shoots down. That's the keystroke."

*(Let the click sound carry. Don't talk over it.)*

**[THE SCALE — 0:20–0:30]**
*Pour or spread them all on the desk. Show the pile.*

> "I need 84 of these mounted, wired, and positioned over every single key. All at the same height. All firing in sync."

**[CTA — 0:30–0:40]**

> "Week 3 I fire the first one. Follow to see if I survive the wiring."

---

### Shot List
- [ ] Box arriving or being carried to desk (even just pulling it from inside)
- [ ] Cutting the box open (overhead angle)
- [ ] Pulling out solenoids — show the quantity
- [ ] Close-up of single solenoid, rotating it in your hand
- [ ] Manually triggering one (attach a 9V battery to the leads — it WILL fire and it's very satisfying)
- [ ] Overhead shot: all solenoids spread on the desk or table

### Edit Notes
- **THE BEST SHOT IN THIS VIDEO:** manually trigger a single solenoid with a 9V battery close-up. The click sound and the physical snap of the plunger is extremely satisfying and will drive re-watches.
- Slow motion on the manual trigger if your phone supports it (0.5x is fine)
- Keep it raw. Don't over-edit this one. The realness is the point.
- Sound design: amplify the click sounds slightly. Don't add music under the demonstration sections.
- Consider cutting this to 2 versions: 30sec "reel" version and a slightly longer 60sec "explainer" version for YouTube Shorts.

---

---

## VIDEO 4: First Keystroke
**Title:** "Day 21: The first key press"
**Platform:** All 4
**Length:** 45–60 seconds
**When to post:** Week 3, after 4×4 test plate success

---
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

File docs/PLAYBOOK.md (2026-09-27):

# Playbook — how to think about this project

*Written July 2026 by Claude Fable 5 as a handoff to future models (Opus and beyond). CLAUDE.md holds the facts; this file holds the reasoning patterns that produced them. Every heuristic below caught a real error or prevented one on this build. Read this once at the start of any session that involves design, debugging, or a decision.*

---

## 1. The prime directive: the part in hand beats the model

Every major correction on this project came from physical reality contradicting an assumption:
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

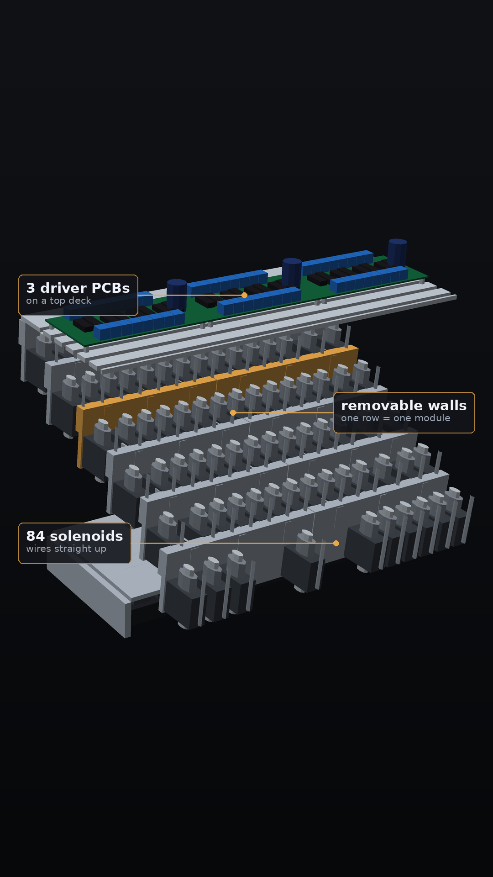
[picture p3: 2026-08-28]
media/new_plate_exploded_still_labeled.png

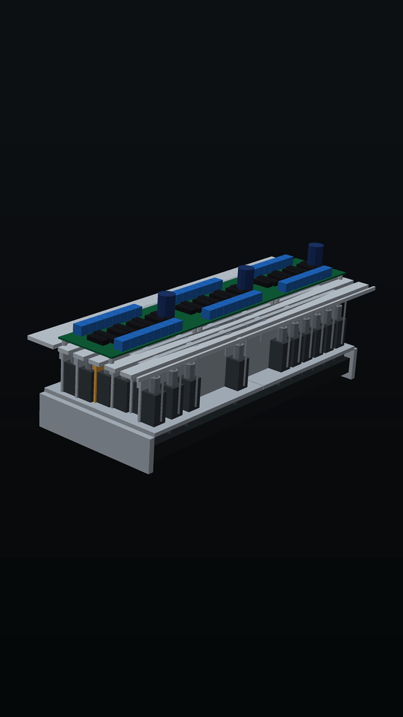
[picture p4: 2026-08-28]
media/new_plate_broll.gif

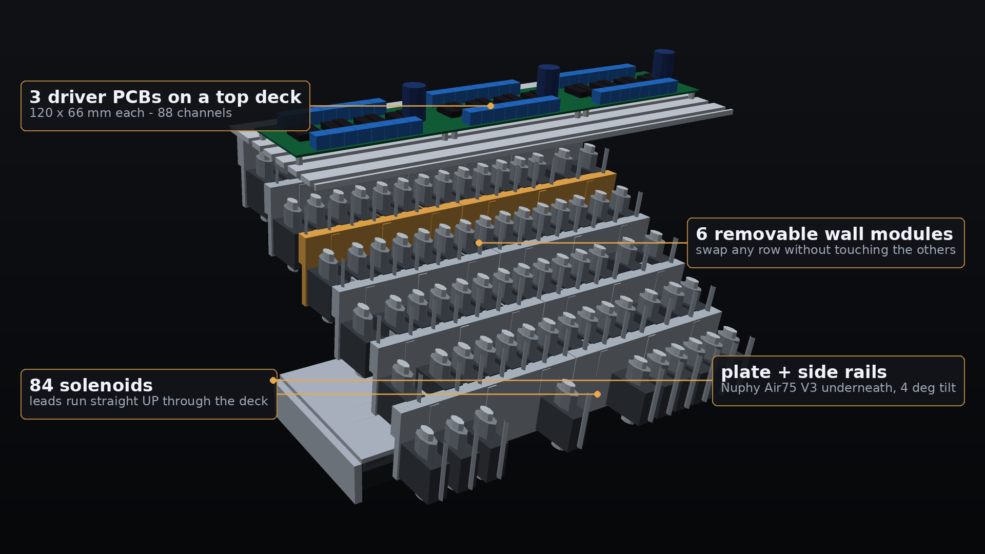
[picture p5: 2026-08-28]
media/new_plate_exploded_wide_labeled.png

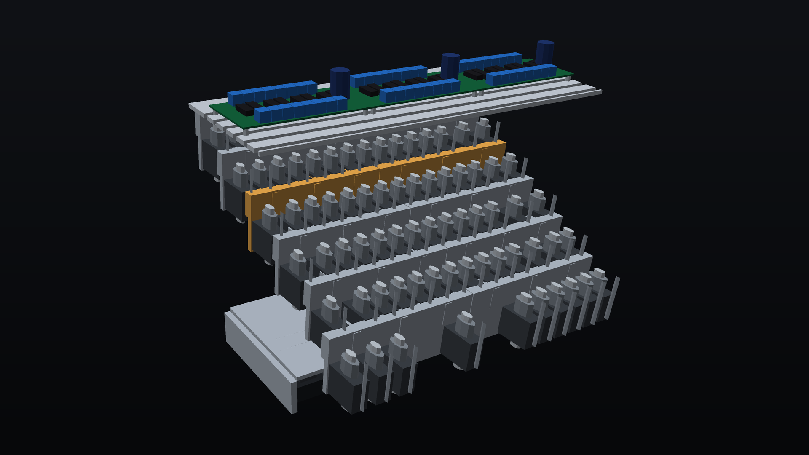
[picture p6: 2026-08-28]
media/new_plate_exploded_wide.png

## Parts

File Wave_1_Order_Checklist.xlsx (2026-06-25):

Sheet: Master Order
Physical AI Agent — Complete Parts List (audited against PRD v2.2 + Build Walkthrough)
Wave 1 (order today, weeks 1–6) + Wave 2 (order week 6) + items the original walkthrough missed.
Status column has a dropdown: To order → Ordered → Arrived → Verified. Color updates automatically.
Status | Item | Qty | Source | Unit Cost | Line Total | Needed By | Search / Link | Notes / Why
WAVE 1 — Solenoid matrix (long-lead)
To order | 5N/10mm push-pull solenoid (30×16×15mm body, 6×58mm plunger) | 100 | AliExpress / Alibaba (bulk) | $3.50 |  | Wk 2 | aliexpress.com/wholesale?SearchText=DC+12V+5N+10mm+solenoid+30x16x15 | DECISION: Big-solenoid path (5N/10mm, 300mA, 30×16×15mm). Fits 19mm pitch with ~1.5–2mm walls. Stroke trimmed via raised CAD plate; force is fine at low end of curve. RISK FLAGGED: heavy 13g steel plunger ≈ 3× slower than JF-0420B-class reference → pushes PRD §6.3 latency budget from 82ms toward ~100ms. See Build Notes sheet. Qty 100 leaves 16 spares from the 84-key matrix (DOA/burnouts/test rig). Unit cost estimate $3.50 — AliExpress/Alibaba bulk; update with actual quote.
WAVE 1 — Target keyboard
To order | Nuphy Air75 V3 + Blush Nano switches | 1 | nuphy.com | $130.00 |  | Wk 3 | nuphy.com | 84-key 75% low-profile. Hot-swappable. MUST select Blush Nano linear switches at checkout.
To order | Spare Blush Nano switches | 30 | nuphy.com | $1.88 |  | Wk 3 | nuphy.com — Blush Nano switches | BUMPED 8→30 for big-solenoid plan. Steel plungers + higher impact energy raise switch-wear risk (PRD R-02b). Hot-swap means no soldering. Keep extras dry-bagged.
To order | Double-sided VHB mounting tape | 1 | Amazon — 3M VHB | $12.00 |  | Wk 3 | amazon.com/s?k=3M+VHB+tape | GAP — PRD §4.2.1 requires keyboard to be fixed to workbench with VHB tape to prevent shifting under repeated strikes. Not on walkthrough's shopping list.
WAVE 1 — Microcontrollers
To order | Arduino Mega 2560 (genuine or compatible) | 1 | Amazon | $25.00 |  | Wk 2 | amazon.com/s?k=Arduino+Mega+2560 | Keyboard controller. Larger SRAM + extra UART vs Uno. Genuine $45 / compatible $15–25.
To order | Arduino Uno R3 (genuine or compatible) | 1 | Amazon | $20.00 |  | Wk 7 | amazon.com/s?k=Arduino+Uno+R3 | Gantry controller. Order in Wave 1 to avoid a second shipment.
WAVE 1 — Driver electronics
To order | 74HC595 shift registers, DIP-16 through-hole | 12 | Amazon multipack | $1.00 |  | Wk 2 | amazon.com/s?k=74HC595+DIP-16 | 11 used, 1 spare. THROUGH-HOLE only, not SMD.
To order | ULN2803A Darlington arrays, DIP-18 through-hole | 12 | Amazon multipack | $1.50 |  | Wk 2 | amazon.com/s?k=ULN2803A+DIP-18 | 11 used, 1 spare. Through-hole only.
To order | IC sockets: DIP-16 (×12) + DIP-18 (×12) | 1 | Amazon multipack | $10.00 |  | Wk 5 | amazon.com/s?k=IC+sockets+DIP-16+DIP-18 | ALWAYS socket ICs. Saves rework on the 22-IC driver board.
To order | Perfboard, large (~10×15 cm) | 3 | Amazon multipack | $5.00 |  | Wk 5 | amazon.com/s?k=10x15cm+perfboard | Single-sided through-hole. May need to bridge two boards for the 11-SR + 11-ULN driver.
To order | Capacitors: 4700µF 25V ×2, 0.1µF ceramic ×50+ | 1 | Amazon multipack | $15.00 |  | Wk 5 | amazon.com/s?k=4700uF+25V+capacitor+0.1uF+ceramic+kit | 0.1µF decouple on every IC (22 needed). 4700µF reservoir on 12V rail per PRD §4.5.3.
To order | Pin headers, male 0.1" pitch (40-pin strips) | 1 | Amazon | $10.00 |  | Wk 2 | amazon.com/s?k=0.1+inch+pin+headers+male | Snap to length. Used for driver board outputs and breadboard work.
To order | Dupont jumper wires (M-M, M-F, F-F kit) | 1 | Amazon kit | $10.00 |  | Wk 2 | amazon.com/s?k=dupont+jumper+wire+kit | All three genders. For breadboard + Arduino-to-board jumpers.
WAVE 1 — Prototyping (Week 2) — GAPS the walkthrough missed
To order | Breadboard kit (1 full + 2 half-size) | 1 | Amazon | $10.00 |  | Wk 2 | amazon.com/s?k=breadboard+kit+830 | GAP — Week 2 step 1 says "Wire one 74HC595 to the Arduino Mega on a breadboard." No breadboard on walkthrough's list.
To order | LED assortment kit (5mm, mixed colors) | 1 | Amazon | $8.00 |  | Wk 2 | amazon.com/s?k=5mm+LED+assortment | GAP — Week 2 walk-test needs LEDs on the SR outputs. Also useful as status indicators on channels 84–87 per Week 5.
To order | Resistor kit (1/4W, includes 220Ω, 330Ω, 1kΩ, 10kΩ) | 1 | Amazon | $10.00 |  | Wk 2 | amazon.com/s?k=1/4W+resistor+kit+assortment | GAP — Need current-limiting resistors for the LED walk-test, plus pull-ups/pull-downs anywhere logic needs them.
WAVE 1 — Wire and termination
To order | Solid-core hookup wire, 22 AWG, 6+ colors | 1 | Amazon kit | $15.00 |  | Wk 5 | amazon.com/s?k=22+AWG+solid+hookup+wire+kit | ≥5 colors, 30 ft each minimum. For perfboard point-to-point wiring.
To order | Stranded hookup wire, 22 AWG, multi-color | 1 | Amazon kit | $18.00 |  | Wk 6 | amazon.com/s?k=22+AWG+stranded+wire+kit | GAP — Week 6 step 3 says "Use 22 AWG stranded wire" for all 84 solenoid runs. Walkthrough's list only has solid-core, which will fatigue and break on flexing runs.
To order | Stranded silicone wire 18 AWG (red + black, 10ft each) | 1 | Amazon | $15.00 |  | Wk 5 | amazon.com/s?k=18+AWG+silicone+wire+red+black | For 12V power runs from PSU to driver board.
To order | Heat-shrink tubing assortment (2mm, 3mm, 5mm) | 1 | Amazon kit | $10.00 |  | Wk 5 | amazon.com/s?k=heat+shrink+tubing+kit | All wire joints and solenoid leads.
WAVE 1 — Power
To order | 12V 40A switching PSU (S-480-12) | 1 | Amazon | $60.00 |  | Wk 2 | amazon.com/s?k=S-480-12+12V+power+supply | Aluminum-case CCTV style. MUST be 480W not 360W. PRD §4.5.1 notes 50A upgrade optional for +$20 fault margin.
To order | IEC C13 power cord (kettle cord, US plug) | 1 | Amazon | $6.00 |  | Wk 2 | amazon.com/s?k=IEC+C13+power+cord+6ft | GAP — Bare S-480-12 PSUs almost never ship with a mains cord. Skip if you have a spare PC/monitor power cord.
To order | LM2596 buck converter modules | 2 | Amazon multipack | $4.00 |  | Wk 5 | amazon.com/s?k=LM2596+buck+converter | Step 12V → 5V for each Arduino. PRD §4.5.2 specifies one per Arduino for isolation.
WAVE 1 — Mechanical (matrix plate)
To order | PLA filament 1kg | 2 | Amazon / Bambu / Polymaker | $18.00 |  | Wk 3 | amazon.com/s?k=PLA+filament+1kg | 1kg should cover matrix plate + mouse cradle + brackets. Bumped to 2kg for prints-fail margin (the full plate is large).
To order | Silicone tubing 5mm ID, food-grade roll | 1 | Amazon | $10.00 |  | Wk 3 | amazon.com/s?k=5mm+ID+silicone+tubing+food+grade | Cap each of 84 solenoid plungers with 5mm of tubing.
To order | M2 screws + nuts + washers assortment kit | 1 | Amazon | $15.00 |  | Wk 3 | amazon.com/s?k=M2+screws+nuts+assortment | 2 per solenoid × 84 = 168 minimum. Get a kit with 300+ for buffer.
To order | M5 standoffs, 25mm fixed (with 20mm + 30mm spares) | 12 | Amazon | $1.20 |  | Wk 3 | amazon.com/s?k=M5+adjustable+standoff | REVISED for big-solenoid plan. 4× 25mm primary mount + 4× 20mm + 4× 30mm spares to dial plunger-to-keycap gap. Big solenoid (30mm body) + 10mm stroke needs CAD plate ~25mm above keycap top (vs 40–70mm range originally). PRD §4.2.2 — adjustable plunger-to-keycap gap of 1–2mm.
WAVE 1 — Soldering kit
To order | Soldering kit (iron + solder + flux + wick + multimeter) | 1 | Amazon | $80.00 |  | Wk 1 | amazon.com/s?k=Pinecil+V2+soldering+kit | Pinecil V2 + 60/40 leaded solder + flux pen + multimeter. Set status to 'Already own' if you have a temp-controlled iron + multimeter.
WAVE 1 — Host connectivity (MacBook USB-C)
To order | Powered 4-port USB-A hub with USB-C cable | 1 | Amazon — Anker / Sabrent | $25.00 |  | Wk 10 | amazon.com/s?k=powered+USB+hub+4+port+USB-C | GAP — The M4 Pro MacBook is USB-C only. Final rig needs 4 USB-A devices connected: Arduino Mega + Arduino Uno + Logitech B100 mouse + C920 webcam. Self-powered hub avoids bus-power issues with two Arduinos.
To order | USB-A to USB-B cable, 6ft (Arduino spare) | 1 | Amazon | $5.00 |  | Wk 2 | amazon.com/s?k=USB-A+to+USB-B+cable+6ft | GAP — Both Arduinos ship with short USB cables, sometimes only 3ft. Get one longer spare so you don't have to keep the laptop on the bench.
WAVE 1 — Documentation gear (PRD §6.5.2)
To order | Phone tripod (Joby GorillaPod or generic) | 1 | Amazon | $25.00 |  | Wk 1 | amazon.com/s?k=Joby+GorillaPod+phone | Tabletop or floor model. For overhead bench filming.
To order | Clip-on lavalier mic (BOYA BY-M1 or similar) | 1 | Amazon | $30.00 |  | Wk 1 | amazon.com/s?k=BOYA+BY-M1+lavalier | Plug-and-play with phone via Lightning/USB-C adapter. Huge voiceover quality jump.
WAVE 1 — Wire labeling (Week 6 mandate)
To order | Sharpie fine + masking/painter's tape | 1 | Amazon / hardware store | $8.00 |  | Wk 6 | amazon.com/s?k=fine+point+sharpie+painters+tape | GAP — Walkthrough troubleshooting: "Label every wire pair with a Sharpie at both ends, AS YOU WIRE IT, not later." Label-maker tape is on Wave 2 but you wire the keyboard in Wk 6 — too late.
TOOLS — verify owned before Wk 1 (walkthrough §1.1)
To order | Hex key set (M3/M4/M5 metric) | 1 | Amazon / hardware store | $12.00 |  | Wk 7 | amazon.com/s?k=metric+hex+key+set | TOOL — Walkthrough §1.1 lists as "must own". Whole 2020 V-slot ecosystem uses M3/M4/M5 hex. Set status to 'Already own' if you have one.
To order | Digital calipers, 150mm | 1 | Amazon | $18.00 |  | Wk 3 | amazon.com/s?k=digital+calipers+150mm | TOOL — Walkthrough §1.1: required for CAD work (measuring the Nuphy keyboard, key pitch, mouse dimensions). Cheap unit is fine.
To order | Safety glasses | 1 | Amazon / hardware store | $6.00 |  | Wk 1 | amazon.com/s?k=safety+glasses+ANSI | TOOL — Walkthrough §1.1: "mandatory while soldering". Don't skip.
To order | Wire strippers (auto-adjusting) | 1 | Amazon | $18.00 |  | Wk 2 | amazon.com/s?k=auto+wire+strippers | TOOL — Walkthrough §1.1: "strongly recommended". Self-adjusting type saves tons of time on 84+ wire pairs.
To order | Heat-resistant silicone work mat | 1 | Amazon | $15.00 |  | Wk 1 | amazon.com/s?k=silicone+soldering+mat | TOOL — Walkthrough §1.1. Protects desk + organizes screws via magnetic sections (some have them).
WAVE 2 — Gantry frame (order Week 6 per walkthrough)
To order | 2020 V-slot aluminum extrusion (4m total, pre-cut if available) | 1 | Amazon / OpenBuilds | $50.00 |  | Wk 7 | openbuilds.com — 2020 V-slot | Cuts needed: 2× 400mm (X), 2× 280mm (Y), 4× 60mm corner stiffeners. Order pre-cut if vendor offers.
To order | 2020 corner brackets + T-nuts (100pc assortment) | 1 | Amazon kit | $25.00 |  | Wk 7 | amazon.com/s?k=2020+corner+bracket+T+nut+kit | Frame assembly hardware.
To order | NEMA 17 stepper motors (1.5-1.7A) | 2 | Amazon | $12.50 |  | Wk 7 | amazon.com/s?k=NEMA+17+stepper+1.7A | Standard 3D-printer steppers.
To order | CNC Shield V3 + 2× A4988 drivers + heatsinks | 1 | Amazon kit | $25.00 |  | Wk 7 | amazon.com/s?k=CNC+Shield+V3+A4988+kit | Comes as kit; ignore the A-axis driver.
To order | GT2 belt 6mm (3m) + 2× 20T pulleys (5mm bore) | 1 | Amazon | $15.00 |  | Wk 7 | amazon.com/s?k=GT2+belt+6mm+20T+pulley | Pulleys must match stepper shaft (5mm).
To order | V-slot wheels (×8) + bearings + spacers | 1 | Amazon / OpenBuilds kit | $25.00 |  | Wk 7 | amazon.com/s?k=V-slot+wheel+kit+OpenBuilds | Delrin or POM wheels. 4 per axis.
To order | Microswitch limit switches | 4 | Amazon multipack | $2.00 |  | Wk 7 | amazon.com/s?k=microswitch+limit+switch | 2 used (X-min, Y-min), 2 spares.
WAVE 2 — Mouse end-effector
To order | SG90 micro servo (multipack) | 2 | Amazon | $2.50 |  | Wk 8 | amazon.com/s?k=SG90+servo+5pack | Hobby servos for L/R click levers.
To order | Logitech B100 USB optical mouse | 1 | Amazon | $10.00 |  | Wk 8 | amazon.com/s?k=Logitech+B100 | Sacrifice mouse. Any cheap wired optical works.
To order | Hard plastic mousepad (large, ~90×40cm) | 1 | Amazon | $15.00 |  | Wk 8 | amazon.com/s?k=hard+plastic+mousepad+90x40 | Hard surface for consistent optical tracking. Walkthrough troubleshooting flags cloth pads as a jitter source.
WAVE 2 — Vision
To order | Logitech C920 webcam (refurbished OK) | 1 | Amazon | $70.00 |  | Wk 9 | amazon.com/s?k=Logitech+C920 | Or comparable 1080p. Refurb $40–50 fine. PRD §4.4.
To order | Articulating arm / microphone-style boom mount | 1 | Amazon | $20.00 |  | Wk 9 | amazon.com/s?k=articulating+webcam+arm | Clamps to bench, holds webcam 250–350mm above screen.
To order | Circular polarizing filter (clip-on for webcam) | 1 | Amazon | $10.00 |  | Wk 9 | amazon.com/s?k=circular+polarizing+filter+webcam | Reduces screen glare. PRD §4.4.
To order | LED task lamp (diffuse, ≥300 lux at screen) | 1 | Amazon — IKEA / cheap LED | $25.00 |  | Wk 9 | amazon.com/s?k=LED+task+lamp+dimmable | GAP — PRD §4.4 explicitly requires: "One indirect, diffuse LED task lamp providing ≥300 lux at the screen surface." Wasn't on either of walkthrough's waves. Critical for stable OCR/template matching.
WAVE 2 — Base + cabling + safety
To order | Plywood or HDPE base board, 600×450×12mm | 1 | Local hardware store | $20.00 |  | Wk 7 | Home Depot / Lowes — cut to size | Carries everything. Cut to size at the store.
To order | Cable raceway / wire chase, 1m | 1 | Amazon | $10.00 |  | Wk 12 | amazon.com/s?k=wire+raceway+1m | Keeps rear of rig tidy.
To order | E-stop pushbutton, mushroom head, NC contact | 1 | Amazon industrial | $15.00 |  | Wk 7 | amazon.com/s?k=E-stop+mushroom+NC | Wires into PSU remote-disable line. PRD §4.5.4.
To order | DC relay (40A, 5V coil) | 1 | Amazon | $10.00 |  | Wk 7 | amazon.com/s?k=40A+5V+relay+module | Optional alternative if PSU lacks remote-disable terminal. Switches 12V to actuators.
To order | XT60 or screw-terminal connectors (12V distribution) | 1 | Amazon | $10.00 |  | Wk 7 | amazon.com/s?k=XT60+connector+pack | Whichever you prefer for clean 12V distribution.
To order | Misc: zip ties + label-maker tape + electrical tape | 1 | Amazon / hardware | $15.00 |  | Wk 12 | amazon.com/s?k=zip+tie+assortment+label+maker | Final cable management.
OPTIONAL / RECOMMENDED ADD-ONS
To order | Helping-hands or PCB holder | 1 | Amazon | $20.00 |  | Wk 5 | amazon.com/s?k=helping+hands+PCB+holder | OPTIONAL — Makes the 260-joint Week 5 solder session much less painful. Highly recommended for first-time builders.
To order | Matte anti-glare film for MacBook screen | 1 | Amazon | $15.00 |  | Wk 9 | amazon.com/s?k=14+inch+MacBook+matte+screen+protector | OPTIONAL — PRD §4.4: "matte anti-glare film optional on the MacBook screen if reflections are persistent." Buy if polarizer alone isn't cutting reflections.
To order | 12V 50A PSU upgrade (S-600-12) | 1 | Amazon | $80.00 |  | Wk 2 | amazon.com/s?k=S-600-12+12V+power+supply | OPTIONAL — PRD §4.5.1 notes 50A upgrade (~+$20) gives margin for fault-mode scenarios. Skip if buying the 40A above.
To order | Power strip with switch (mains kill) | 1 | Amazon | $15.00 |  | Wk 1 | amazon.com/s?k=power+strip+with+switch | OPTIONAL — Convenient one-touch mains kill in addition to the E-stop on the 12V side.
To order | USB-A to USB-C adapter (2-pack) | 1 | Amazon | $8.00 |  | Wk 2 | amazon.com/s?k=USB-A+to+USB-C+adapter | OPTIONAL — Backup if the powered hub fails or for testing one Arduino at a time on the MacBook directly.
BIG-SOLENOID ADAPTATIONS — empirical-validation + thermal mitigation (added per build review)
To order | 80mm USB cooling fan (5V, quiet, with mesh guard) | 1 | Amazon | $9.00 |  | Wk 6 | amazon.com/s?k=80mm+USB+fan+quiet | ADDED for big-solenoid plan. 100×300mA holding current = up to 30A peak — driver ICs (ULN2803) and PSU will heat-soak under PRD §7 1-hour endurance test. Aim airflow across the driver board and behind solenoid bank. Powered by spare USB-A on the hub.
To order | Prototype test kit: same 5N solenoid ×4, expedited | 1 | Amazon (fast ship) | $22.00 |  | Wk 1 | amazon.com/s?k=DC+12V+push+pull+solenoid+5N | ADDED — recommended but skippable. Buy 4 of the SAME solenoid from a fast-shipping source so you can validate force/keystroke/CAD-plate gap on the actual Nuphy Air75 V3 BEFORE the 100-unit bulk order arrives. Cheap insurance against discovering form-factor or actuation issues at week 6. Set status to 'Skip' if you can wait 4–6 weeks for the bulk order to land before any testing.
To order | Extra 22 AWG stranded wire — 100 ft additional | 1 | Amazon | $12.00 |  | Wk 6 | amazon.com/s?k=22+AWG+stranded+silicone+wire+100ft | ADDED — Big solenoids draw 300mA each = same wire gauge OK, but 100 solenoids (vs 90) need an extra ~30ft. Plus the bigger solenoid bodies push the matrix plate higher, so wire runs from the plate down to the driver board grow ~50mm each. Safer to over-order.
 |  |  |  | WAVE 1 (essentials)
 |  |  |  | Tools (verify owned — only counted if buying)
 |  |  |  | WAVE 2 (deferred to week 6)
 |  |  |  | Optional / recommended
 |  |  |  | PROJECT GRAND TOTAL (all categories)
 |  |  |  | Wave 1 + Wave 2 (essentials only)
 |  |  |  | PRD budget ceiling reference | $1500.00

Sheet: Order Sequence
Order in this sequence today to avoid being blocked
Wave 1 essentials + tools + critical gaps. Wave 2 stays deferred to week 6.
Cart | Priority | What to order | Why it goes here
Nuphy.com cart | 1 — TODAY | Nuphy Air75 V3 + Blush Nano switches + 8 spare switches | Separate vendor from Amazon. Order in parallel. MUST select Blush Nano LINEAR switches at checkout.
Amazon cart A — long-lead | 1 — TODAY | 90× JF-0420B solenoids | Even on Amazon this can ship slowest. Order first so you're not blocked Wk 2–3.
Amazon cart B — electronics + tools | 2 — TODAY | Arduino Mega + Uno, 74HC595 ×12, ULN2803A ×12, soldering kit, USB hub, breadboard + LEDs + resistors, jumper kit, perfboard, IC sockets, headers, caps, heat-shrink, both wire types (solid + stranded 22 AWG, silicone 18 AWG), 12V PSU, IEC cord, buck converters | Everything needed for Weeks 2–5. Single cart. Amazon Prime gets it in days.
Amazon cart C — mechanical + vision-prep + docs | 3 — TODAY | PLA filament 2kg, silicone tubing, M2 hardware, M5 standoffs, VHB tape, Sharpie+tape, safety glasses, calipers, wire strippers, silicone mat, hex keys, phone tripod, lavalier mic | Weeks 3–6 mechanical work + documentation gear (PRD requires from Wk 1).
LATER — Wave 2 (Wk 6) | DEFERRED | 2020 extrusion, NEMA 17 steppers, CNC Shield + A4988s, GT2 belts/pulleys, V-slot wheels, limit switches, SG90 servos, B100 mouse, mousepad, C920 webcam, articulating arm, polarizer, LED task lamp, plywood base, raceway, E-stop, relay, XT60s, zip ties/labels | Walkthrough's plan: absorb learnings from Weeks 1–6 before committing to gantry/vision spend.
OPTIONAL — your call | Today or skip | Helping-hands holder, matte screen film, 50A PSU upgrade, power strip, USB-A→C adapters | Nice-to-haves. Helping-hands strongly recommended before the Wk 5 solder marathon.

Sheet: Audit Trail
Coverage audit — every line in the walkthrough + PRD mapped to a row in Master Order
Source line / requirement | Doc reference | Covered? | Notes
84 JF-0420B solenoids (ordered 90) | Walkthrough §2.1 | Yes | Sourced from Amazon (fast) per your call. +$120 vs AliExpress.
74HC595 ×12 | Walkthrough §2.1 | Yes
ULN2803A ×12 | Walkthrough §2.1 | Yes
Arduino Mega 2560 | Walkthrough §2.1 | Yes
Arduino Uno | Walkthrough §2.1 | Yes | Used in Wave 2 (gantry) but ordered now to consolidate shipments.
Soldering kit | Walkthrough §2.1 | Yes | Mark 'Already own' if you have temp-controlled iron + multimeter.
Nuphy Air75 V3 + Blush Nano | Walkthrough §2.1 | Yes
Spare Blush Nano switches ×8 | Walkthrough §2.1 | Yes
12V 40A PSU | Walkthrough §2.1 | Yes
LM2596 buck converters ×2 | Walkthrough §2.1 | Yes
Perfboard ×3 | Walkthrough §2.1 | Yes
22 AWG solid-core hookup wire | Walkthrough §2.1 | Yes
18 AWG silicone wire | Walkthrough §2.1 | Yes
IC sockets DIP-16 + DIP-18 | Walkthrough §2.1 | Yes
Pin headers | Walkthrough §2.1 | Yes
Dupont jumpers | Walkthrough §2.1 | Yes
Capacitors (4700µF + 0.1µF) | Walkthrough §2.1 | Yes
Heat-shrink | Walkthrough §2.1 | Yes
Silicone tubing 5mm ID | Walkthrough §2.1 | Yes
PLA filament | Walkthrough §2.1 | Yes | Bumped to 2kg for buffer.
M2 screws/nuts | Walkthrough §2.1 | Yes
M5 standoffs | Walkthrough §2.1 | Yes
Phone tripod | Walkthrough §2.1 | Yes
Lavalier mic | Walkthrough §2.1 | Yes
2020 V-slot extrusion 4m | Walkthrough §2.2 | Yes (Wave 2)
Corner brackets + T-nuts | Walkthrough §2.2 | Yes (Wave 2)
NEMA 17 steppers ×2 | Walkthrough §2.2 | Yes (Wave 2)
CNC Shield + A4988 ×2 | Walkthrough §2.2 | Yes (Wave 2)
GT2 belt + pulleys | Walkthrough §2.2 | Yes (Wave 2)
V-slot wheels + bearings | Walkthrough §2.2 | Yes (Wave 2)
Limit switches ×4 | Walkthrough §2.2 | Yes (Wave 2)
SG90 servos ×2 | Walkthrough §2.2 | Yes (Wave 2)
Logitech B100 mouse | Walkthrough §2.2 | Yes (Wave 2)
Mousepad | Walkthrough §2.2 | Yes (Wave 2)
Logitech C920 webcam | Walkthrough §2.2 | Yes (Wave 2)
Articulating webcam arm | Walkthrough §2.2 | Yes (Wave 2)
Circular polarizer | Walkthrough §2.2 | Yes (Wave 2)
Plywood/HDPE base 600×450 | Walkthrough §2.2 | Yes (Wave 2)
Cable raceway | Walkthrough §2.2 | Yes (Wave 2)
E-stop pushbutton | Walkthrough §2.2 | Yes (Wave 2)
DC relay 40A | Walkthrough §2.2 | Yes (Wave 2)
XT60 / screw terminals | Walkthrough §2.2 | Yes (Wave 2)
Zip ties + labels + tape | Walkthrough §2.2 | Yes (Wave 2)
Breadboard for Wk 2 prototype | Walkthrough §3 Wk 2 | Added (GAP) | Step 1: "Wire one 74HC595 to the Arduino Mega on a breadboard."
LEDs for Wk 2 walk-test | Walkthrough §3 Wk 2 | Added (GAP) | Step 1: "LED-test sketch that walks lights down the 8 outputs."
Current-limiting resistors | Walkthrough §3 Wk 2 | Added (GAP) | Required to use the LEDs safely.
22 AWG STRANDED wire | Walkthrough §3 Wk 6 | Added (GAP) | Step 3: "Use 22 AWG stranded wire" — list only has solid-core.
Wire labels (Sharpie + tape) | Walkthrough §3 Wk 6 + Pitfalls | Added (GAP) | Label-maker tape is in Wave 2 but needed before Wave 2 arrives.
VHB tape for keyboard mounting | PRD §4.2.1 | Added (GAP) | "The keyboard is fixed to the workbench with double-sided VHB tape."
LED task lamp ≥300 lux diffuse | PRD §4.4 | Added (GAP) | "One indirect, diffuse LED task lamp providing ≥300 lux at the screen surface."
USB hub (M4 MacBook is USB-C) | Inferred from §4.4 + §4.3.3 | Added (GAP) | Final rig needs 4 USB-A devices: 2 Arduinos + webcam + sacrifice mouse.
PSU mains cord (IEC C13) | Inferred | Added (GAP) | Bare S-480-12 PSUs ship without mains cord.
Hex key set M3/M4/M5 | Walkthrough §1.1 | Added (TOOL) | Listed as 'tools you must own'. Mark 'Already own' if applicable.
Digital calipers 150mm | Walkthrough §1.1 | Added (TOOL) | Required for CAD measuring.
Safety glasses | Walkthrough §1.1 | Added (TOOL) | Mandatory while soldering.
Wire strippers | Walkthrough §1.1 | Added (TOOL) | Auto-adjusting strongly recommended.
Heat-resistant work mat | Walkthrough §1.1 | Added (TOOL)
Helping-hands / PCB holder | Implied for Wk 5 | Added (OPT) | Recommended for the 260-joint solder session.
Matte anti-glare film | PRD §4.4 | Added (OPT) | PRD calls out as 'optional'.
50A PSU upgrade | PRD §4.5.1 | Added (OPT) | PRD: '+$20 for fault-mode margin'.

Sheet: Legend
Color legend & how to use this workbook
Color | Meaning
Orange-tinted row | GAP — item the walkthrough shopping list missed but build steps or PRD require. Audited and added by me.
Gray row | Tool that's listed as 'must own' in walkthrough §1.1, OR an optional add-on. Mark 'Already own' or 'Skip' if not needed.
Light-gray row | Wave 2 — deferred to week 6 per the walkthrough's recommendation.
Green status | Verified — part is in hand and tested.
Blue status | Arrived — physically here, not yet tested.
Yellow status | Ordered — order placed, in transit.
Salmon status | To order — not yet placed.
Dark gray status | Skip — you've decided not to buy this item.
Recommended workflow
1. | Open Order Sequence tab. Place the 4 carts described there today.
2. | As you place each cart, set those items to 'Ordered' (yellow).
3. | As boxes arrive over the next 1–2 weeks, flip to 'Arrived' (blue).
4. | After bench-testing a part, flip to 'Verified' (green).
5. | Audit Trail tab proves nothing from the PRD or walkthrough was missed.

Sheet: Build Notes
PHYSICAL AI AGENT — BIG-SOLENOID BUILD NOTES
Decision: ordering 100× DC 12V 5N/10mm push-pull solenoids (30×16×15mm body, 6×58mm plunger, 300mA).
These notes capture the engineering risks this choice creates and the mitigations baked into the order.
RISK 1 — Latency budget (PRD §6.3, acceptance ≤100ms in 95% of trials)
Reference JF-0420B-class plunger: ~1g, ~3N peak. The 6×58mm steel plunger in the chosen solenoid is ~13g.
Travel-time estimate: at 5N peak force and 13g mass, acceleration ≈ 380 m/s². To traverse a ~5mm trimmed
stroke and clear the 1.4mm Blush Nano actuation distance, mechanical travel ≈ 5–6ms (vs ~2ms for 1g plunger).
Adds ~3–4ms to the 82ms PRD latency total → ~85–86ms estimated. Still inside the 100ms ceiling, but the
margin is now ~15ms instead of ~18ms. Any other slowdown (USB jitter, vision frame skip) eats into it fast.
MITIGATION: keep the rest of the pipeline tight. Profile actual key-down→signal-released latency on the
4-unit prototype kit BEFORE wiring all 84. If empirical mechanical latency >8ms, consider stroke-limiting
the plate to ~3mm of effective travel or moving to a lighter aluminum plunger (machined replacement).
RISK 2 — Switch wear (PRD R-02b)
Steel plunger striking the Blush Nano stem at higher kinetic energy than design-reference. Damage modes:
cracked stem, deformed contact leaf, intermittent actuation. Hot-swap means repair is fast — but only if
you have spares.
MITIGATION: 5mm food-grade silicone tubing on every plunger tip (already in the parts list, row 38) +
30 spare Blush Nano switches (bumped from 8). Inspect first-row keys after the 1-hour endurance test.
RISK 3 — Build tolerance on 19mm key pitch
Solenoid bodies are 16×15mm; key pitch is 19.05mm. That leaves 1.5–2mm of wall between adjacent
solenoids in the matrix plate. Any FDM print warpage, solenoid OD variance, or plate skew will cause
binding. 3D printing tolerance on consumer FDM (Bambu/Prusa) is typically ±0.2mm per slot — feasible
but unforgiving.
MITIGATION: print one 4-cell test fixture FIRST with the prototype kit. Verify all 4 solenoids drop in
freely. Tune slot dimension before committing to the full 84-slot plate (which is a 12+ hour print).
RISK 4 — Unit-to-unit force variance (cheap bulk solenoids)
Expect ±20–25% force variance across a 100-unit batch from AliExpress/Alibaba. Some keys may under-actuate.
MITIGATION: bench-test each solenoid at 12V before mounting. Sort into 'strong / nominal / weak' piles.
Use the strong ones on the lower row (where the plunger has the longest reach over the keycap profile).
Discard any that fail to actuate a key reliably at the design-gap distance — extra reason to have spares.
RISK 5 — Thermal under endurance test (PRD §7)
Holding current 300mA × N keys-held-simultaneously. Realistic peak ~7 keys = 2.1A through the driver,
plus brief surges from key transitions. ULN2803 packages will heat up. 1-hour acceptance test = sustained.
MITIGATION: 80mm USB fan added to the parts list (row 88). Mount over the driver board.
RISK 6 — Repairability / spares
100-unit bulk order with 4–6 week lead time = no quick replacements mid-build.
MITIGATION: 4-unit fast-ship prototype kit (row 89) doubles as field-repair spares once the bulk lands.
84 solenoids in the matrix + 16 spares from the bulk order = comfortable.
WHAT TO DO IF EMPIRICAL TESTING FAILS
If the prototype kit reveals that the big solenoid can't hit PRD §6.3 latency or §7 endurance:
Option A — keep the bulk solenoids, lighten the plunger (drill out steel core or machine a 2g aluminum replacement).
Option B — return/resell the bulk and pivot to JF-0420B-class via Alibaba bulk order (4–6 wk delay, ~$450).
Option C — accept >100ms latency for v1, treat as known limitation in the PRD acceptance writeup,
document in the build log, and revisit for v2.
Make this Go/No-Go call at end of Week 2 (after prototype kit is in hand).
CHANGES vs ORIGINAL ORDER
• Solenoid row 7: JF-0420B @ qty 90 @ $6 → 5N/10mm @ qty 100 @ $3.50 (–$190 if AliExpress price holds)
• Spare switches row 10: qty 8 → qty 30 (+$41)
• M5 standoffs row 40: 40–70mm adjustable ×4 → 25mm fixed ×12 (mixed lengths) (+$11)
• ADDED row 88: 80mm USB cooling fan (+$9)
• ADDED row 89: 4-unit fast-ship prototype test kit (+$22)
• ADDED row 90: extra stranded wire (+$12)
Net cost change vs the JF-0420B-Amazon line: roughly –$95 if AliExpress holds $3.50/unit.

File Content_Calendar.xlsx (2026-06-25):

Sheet: 12-Week Calendar
PHYSICAL AI AGENT — Building in Public Content Calendar
12 Weeks · 4 Platforms · Starting from Zero | Tue & Fri posting cadence
Week | Build Phase | Build Goal | Milestone / Story | TikTok / Reels / Shorts | X (Twitter) | Hook Line | Type | Status | Notes | Viral Potential
1 | Concept & Order | Place Wave 1 orders, document the plan | Parts ordered, project launched | Script #1 — 'I'm building a robot that physically types on a keyboard' | Thread: What I'm building + why + 12-week timeline | "This keyboard is about to have 84 tiny robots on it" | Launch | Post Now | Film with Nuphy keyboard in hand. No parts needed. | 🔥🔥🔥
1 | Concept & Order | Place Wave 1 orders, document the plan | The 'why' explainer | Script #2 — 'Why does AI need to physically type?' | Single tweet: 'Software AI only works with apps that cooperate. Physical AI works with everything.' + diagram | "Everyone asks: why not just use software?" | Explainer | Post Now | Whiteboard sketch works fine. Film overhead. | 🔥🔥🔥
2 | Unboxing & Bench Test | Solenoids arrive, bench test single unit | 100 solenoids unboxing | Script #3 — '100 solenoids just arrived from China' | Thread: unbox photo + single solenoid close-up + 9V battery trigger demo | "One hundred solenoids. Each one fires a different key." | Unboxing | Upcoming | Film as soon as box arrives. 9V battery demo = best shot. | 🔥🔥🔥
2 | Unboxing & Bench Test | Solenoids arrive, bench test single unit | First bench test: single solenoid on Arduino | 30-sec clip: solenoid wired to Arduino, fires on command. Show the click. | Tweet: 'Day X. First solenoid fires. It works.' + clip | "5N of force. 20ms. One keystroke." | Milestone | Upcoming | Close-up shot. Slow motion if phone supports it. | 🔥🔥
3 | 4×4 Test Plate | Print 4×4 plate, mount 4 solenoids, fire first key | Script #5 — First actual keystroke on real keyboard | Script #4 — 'Day 21: First key press' (biggest video so far) | Thread: journey from 3D print → mount → first misfire → SUCCESS | "Day 21. First keystroke." | Milestone | Upcoming | START WITH THE SUCCESS SHOT. Then walk back. Film the fail too. | 🔥🔥🔥🔥
3 | 4×4 Test Plate | Print 4×4 plate, mount 4 solenoids, fire first key | The 4×4 types a 4-letter word | Behind-the-scenes: timelapse of plate printing + wiring | Tweet: 4×4 fires all 16 keys in sequence. Video clip. Reply to yourself from Week 1 thread. | "16 solenoids. 4 keys. One word." | Progress | Upcoming | Best word to type first: 'FIRE' or 'MAKE' or 'HI' | 🔥🔥🔥
4 | Wiring Scale-Up | Begin wiring full 84-key matrix, driver PCBs | The wiring grind begins | Timelapse: desk covered in wires. '84 solenoids × 2 leads = 168 wires to route' | Thread: how the multiplexed wiring matrix works (ULN2803 drivers, I2C, etc.) | "168 wires. One keyboard. This is the grind." | Process | Upcoming | This is visually striking. Overhead wide shot of wire chaos. | 🔥🔥
4 | Wiring Scale-Up | Begin wiring full 84-key matrix, driver PCBs | Struggle/mistake post (use real mistake that happened) | Script #5 — 'I ordered 168 wrong screws' (adapt to actual mistake) | Tweet: honest mistake writeup. 'Here's what I got wrong and why it matters' | "I ordered 168 wrong screws." | Struggle | Upcoming | The more honest the better. Comments = community. | 🔥🔥🔥
5 | Full Matrix Assembly | Complete solenoid mounting for all 84 keys | The full matrix assembled (no wiring yet) | Satisfying overhead shot: 84 solenoids mounted in grid. Say nothing. Let the visual land. | Photo tweet: all 84 solenoids mounted. No caption needed except '84/84' | "84/84." | Visual | Upcoming | This image alone is shareable. High quality photo required. | 🔥🔥🔥
5 | Full Matrix Assembly | Complete solenoid mounting for all 84 keys | ASMR / sound-focused clip | Run all 84 solenoids in sequence: no music, no talking. Just the click wave. | Tweet with video: 84 solenoids firing in sequence. 'This is what 84 keystrokes sound like.' | "What does 84 solenoids firing sound like?" | ASMR/Viral | Upcoming | This is your highest viral ceiling moment. Film from multiple angles. | 🔥🔥🔥🔥
6 | Wave 2 Kickoff + Polish | Order Wave 2 parts, test full matrix timing | Full keyboard types a word for the first time | The robot types 'HELLO' — show the keyboard, the screen, the solenoids firing | Thread: 'Week 6. The robot typed its first word.' Screenshot of screen + video | "Week 6. The robot just said hello." | Milestone | Upcoming | Make the first word something emotional or funny. 'HELLO' is perfect. | 🔥🔥🔥🔥
6 | Wave 2 Kickoff + Polish | Order Wave 2 parts, test full matrix timing | Typing speed test vs. human | WPM comparison: my typing speed vs robot's current speed. 'It's slower than me. For now.' | Tweet: current WPM + what max theoretical WPM is. Ask followers to guess. | "I type faster than my robot. For now." | Explainer | Upcoming | Polls work well on X here. 'How fast do you think it can type?' | 🔥🔥
7 | Vision System | Integrate C920 webcam + OCR for screen reading | The robot can now SEE the screen | 'I gave the robot eyes' — webcam + OCR demo reading text off screen | Thread: how template matching + OCR works. What the robot 'sees' vs what we see. | "I gave the robot eyes." | Milestone | Upcoming | Show the camera's POV — what the robot actually sees is compelling. | 🔥🔥🔥
7 | Vision System | Integrate C920 webcam + OCR for screen reading | OCR fail / wrong character recognized | Quick clip: OCR misreads an 'l' as a '1', types the wrong thing. Robot failure is funny. | Tweet: 'The robot read the screen wrong and typed [hilarious wrong output]' | "The robot misread the screen and typed something hilarious." | Struggle | Upcoming | Lean into the humor. Failure content performs consistently. | 🔥🔥🔥
8 | XY Gantry Build | Build Cartesian gantry for mouse movement | Wave 2 parts arrive — the mouse mover | Unboxing V-slot rail + SG90 servos. 'Now the robot needs to move a mouse.' | Thread: why physical mouse movement is harder than keyboard (continuous vs discrete) | "Now it needs to move a mouse." | Unboxing | Upcoming | Contrast with keyboard: keyboard is discrete, mouse is continuous. Good explainer. | 🔥🔥
8 | XY Gantry Build | Build Cartesian gantry for mouse movement | First mouse movement on gantry | Satisfying clip: servo moves the mouse across a mousepad for the first time | Tweet: 'The mouse just moved. Robot has hands AND feet now.' | "The mouse just moved." | Milestone | Upcoming | Show mouse on mousepad. Clean desk for this shot. | 🔥🔥🔥
9 | AI Integration | Connect AI brain to keyboard + vision system | First AI-directed keystroke (AI decides what to type) | Clip: AI reads a prompt, decides what to type, robot physically types it. Full loop. | Thread: the full architecture — LLM → vision → decision → solenoid → keystroke | "For the first time, the AI chose what to type." | Milestone | Upcoming | This is a huge moment. Film from multiple angles. Have the text prompt visible. | 🔥🔥🔥🔥
9 | AI Integration | Connect AI brain to keyboard + vision system | The 'closed loop' explainer | Explainer: 'AI sees screen → decides action → robot acts → AI sees result.' A closed loop. | Thread diagram: the closed feedback loop. Why this is different from software agents. | "The robot sees. The robot decides. The robot acts." | Explainer | Upcoming | This is the most shareable technical explainer. Use a simple diagram. | 🔥🔥🔥
10 | Mouse + Keyboard Combined | Run keyboard + mouse together, first tasks | First combined task: open an app by clicking + typing | 'The robot opened Notepad, clicked in the text field, and typed a sentence.' Full demo. | Thread: what it feels like to watch an AI physically use a computer for the first time | "It opened an app. Without any API." | Milestone | Upcoming | Film the screen AND the robot simultaneously if possible (two phones). | 🔥🔥🔥🔥
10 | Mouse + Keyboard Combined | Run keyboard + mouse together, first tasks | Comparison: software AI vs physical AI | Split screen: ChatGPT using API vs your robot using the actual app. Same task, different methods. | Tweet: 'software agent needs API access. my robot doesn't. here's why that matters.' | "Software agents need permission. Mine doesn't." | Explainer | Upcoming | This is highly shareable in the AI community. Tag relevant accounts. | 🔥🔥🔥
11 | First Real Task | Robot completes a real-world task end-to-end | The robot does something real and useful | Demo: robot searches for something on Google, reads the result, types a summary. End-to-end. | Thread: 'Week 11. The robot just did something I'd do on my computer. Here's the full demo.' | "The robot just used my computer." | Milestone | Upcoming | Make the task visually clear and impressive. Consider: search + screenshot + type summary. | 🔥🔥🔥🔥
11 | First Real Task | Robot completes a real-world task end-to-end | Community challenge: what task should I demo next? | Poll: 'What should the robot do next? (A) Send an email (B) Fill out a form (C) Play a game (D) Code itself' | Twitter poll: same question. Let the community pick. | "What should the robot do next?" | Community | Upcoming | Community choice = community investment = more shares when you post the result. | 🔥🔥
12 | Endurance & Final Demo | PRD endurance test (2hr), final showcase video | The endurance test: 2 hours of continuous typing | Timelapse of 2-hour endurance test. Count the keystrokes. Show any failures. | Thread: final stats — total keystrokes, failure rate, what broke, what held up | "2 hours. 0 fires. 14,400 keystrokes." | Finale | Upcoming | Real stats make this feel earned. Track keystrokes during the test. | 🔥🔥🔥
12 | Endurance & Final Demo | PRD endurance test (2hr), final showcase video | THE FINAL VIDEO — full project recap | 60-90 second recap: Week 1 concept → Week 12 robot using a computer. Start with the end. | Mega-thread: full 12-week recap with best clips from each week. Pin this. | "12 weeks ago this keyboard had no robots on it." | Finale | Upcoming | This is your hero piece. Spend extra time on edit. Archive all weekly footage. | 🔥🔥🔥🔥🔥

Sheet: Video Tracker
VIDEO PRODUCTION TRACKER
# | Title / Hook | Script Status | Filmed | Edited | Captions | Posted (TikTok) | Posted (Reels) | Posted (Shorts) | Posted (X)
1 | I'm building a robot that physically types on a keyboard | ✅ Done | ⬜ | ⬜ | ⬜ | ⬜ | ⬜ | ⬜ | ⬜
2 | Why does AI need to physically type? | ✅ Done | ⬜ | ⬜ | ⬜ | ⬜ | ⬜ | ⬜ | ⬜
3 | 100 solenoids just arrived from China | ✅ Done | ⬜ | ⬜ | ⬜ | ⬜ | ⬜ | ⬜ | ⬜
4 | Day 21: First key press | ✅ Done | ⬜ | ⬜ | ⬜ | ⬜ | ⬜ | ⬜ | ⬜
5 | I ordered 168 wrong screws [or real mistake] | ✅ Done | ⬜ | ⬜ | ⬜ | ⬜ | ⬜ | ⬜ | ⬜
6 | 168 wires. This is the grind. | ⬜ Needed | ⬜ | ⬜ | ⬜ | ⬜ | ⬜ | ⬜ | ⬜
7 | 84/84 — the full matrix is mounted | ⬜ Needed | ⬜ | ⬜ | ⬜ | ⬜ | ⬜ | ⬜ | ⬜
8 | What 84 solenoids firing sounds like [no music] | ⬜ Needed | ⬜ | ⬜ | ⬜ | ⬜ | ⬜ | ⬜ | ⬜
9 | Week 6: The robot just said hello | ⬜ Needed | ⬜ | ⬜ | ⬜ | ⬜ | ⬜ | ⬜ | ⬜
10 | I gave the robot eyes (vision system) | ⬜ Needed | ⬜ | ⬜ | ⬜ | ⬜ | ⬜ | ⬜ | ⬜
11 | For the first time, the AI chose what to type | ⬜ Needed | ⬜ | ⬜ | ⬜ | ⬜ | ⬜ | ⬜ | ⬜
12 | The robot opened an app. Without any API. | ⬜ Needed | ⬜ | ⬜ | ⬜ | ⬜ | ⬜ | ⬜ | ⬜
13 | 12 weeks ago this keyboard had no robots on it | ⬜ Needed | ⬜ | ⬜ | ⬜ | ⬜ | ⬜ | ⬜ | ⬜

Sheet: Hashtag & Copy Bank
HASHTAG & COPY BANK
HASHTAGS — Rotate 3–5 per post. Never all at once.
Category | Hashtags | Usage Note
Core Set (always use) | #buildinpublic #robotics #diy #maker #aiagent | Use 2–3 of these every post
Build Tech | #arduino #solenoid #3dprinting #fusion360 #cad | Rotate based on content
AI Community | #AI #artificialintelligence #llm #machinelearning #aitools | Use on AI-angle posts
Maker Community | #makerspace #electronics #engineering #stem #tinker | Use on build/process posts
Trending / Broad | #buildingthefuture #satisfying #howto #tech #startup | Use sparingly — broad audience
ASMR / Sound posts | #asmr #satisfyingsounds #oddlysatisfying #mechanicalkeyboard | For the solenoid sound videos only
BIO TEMPLATES — Use same bio across all platforms
Short (TikTok/IG) | Building a robot that physically types on a keyboard. 84 solenoids. 12 weeks.
Medium (X/Twitter) | Building a physical AI agent — 84 solenoids, 1 keyboard, 12 weeks. AI that types for real. Follow the build.
Full (YouTube about) | I'm Daniel — building a physical AI agent from scratch. 84 solenoids, one per key, so AI can use a real keyboard. No APIs, no virtual interfaces — just real hardware. 12-week build, weekly updates.

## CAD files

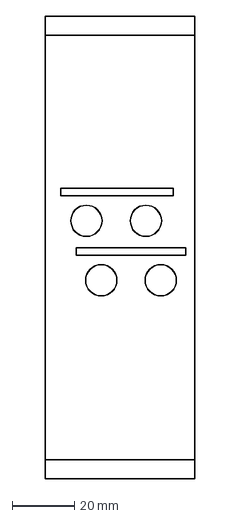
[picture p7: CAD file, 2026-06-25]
2x2 Prototype FINALFINALFINAL.dxf
48.0 x 148.0 mm

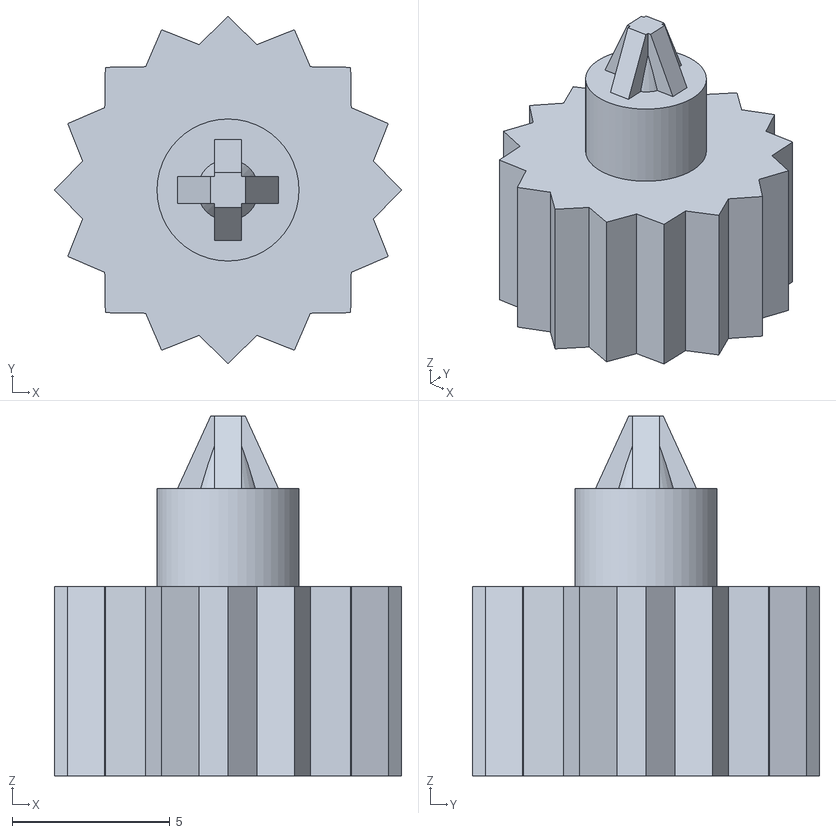
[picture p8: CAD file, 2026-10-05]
cad/driver_tip/Knob_D11_PH1_100.stl
11.0 x 11.0 x 11.4

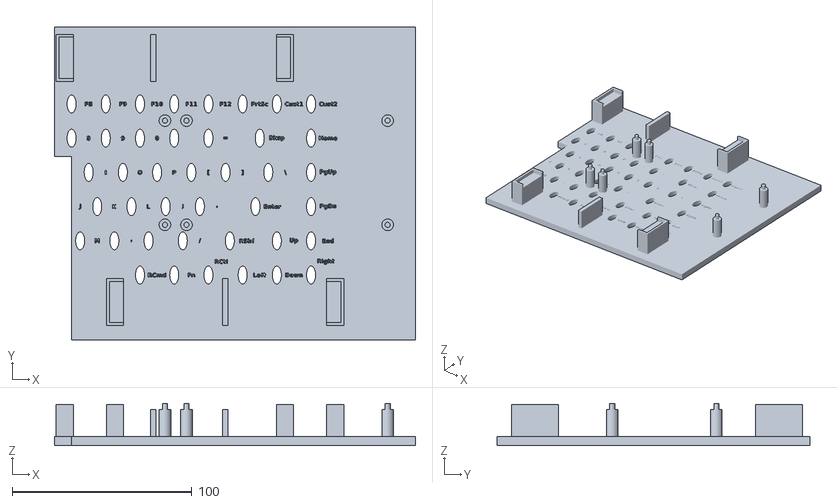
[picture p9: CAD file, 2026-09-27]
cad/table/Table_Right.stl
201.0 x 174.0 x 23.5

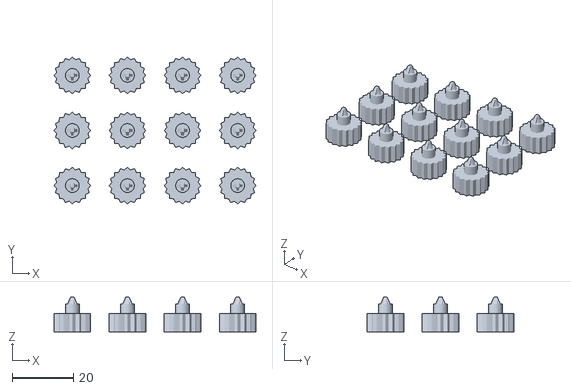
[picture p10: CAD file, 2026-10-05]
cad/driver_tip/Knob_D12_dot2_x12.stl
66.0 x 48.0 x 11.4

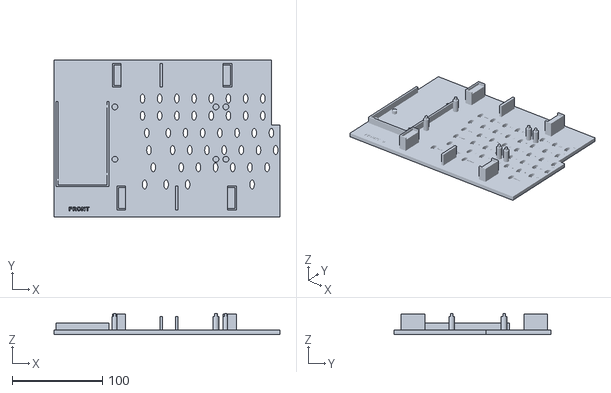
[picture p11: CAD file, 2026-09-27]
cad/table/Table_Left.stl
250.5 x 174.0 x 23.5

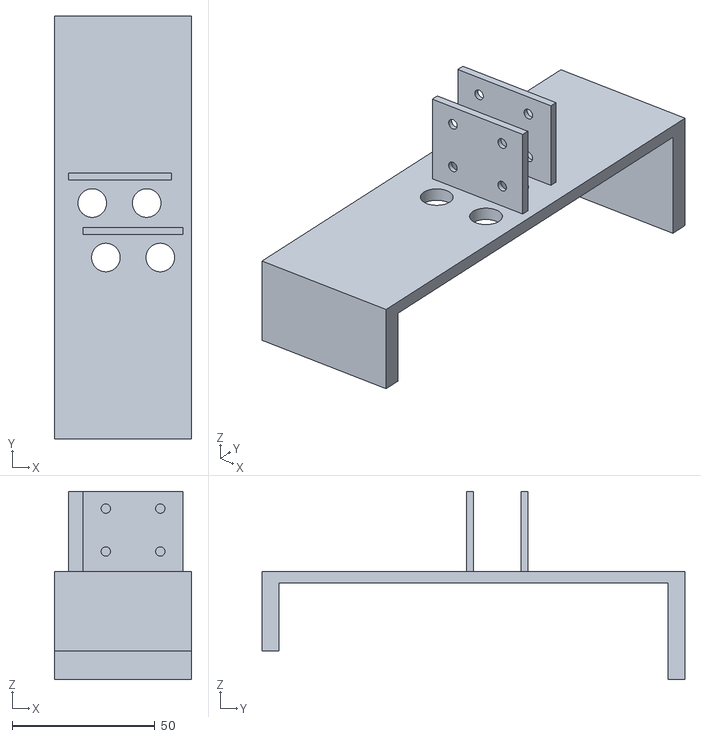
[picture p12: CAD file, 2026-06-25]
Prototype2x2.V2.stl
48.0 x 148.0 x 65.8

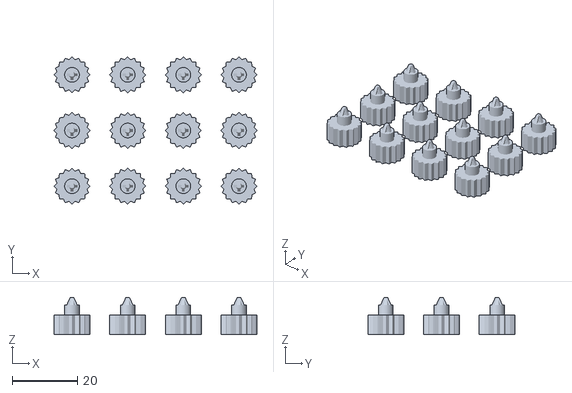
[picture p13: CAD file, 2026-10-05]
cad/driver_tip/smallahhdriverX12.stl
62.0 x 45.0 x 11.4

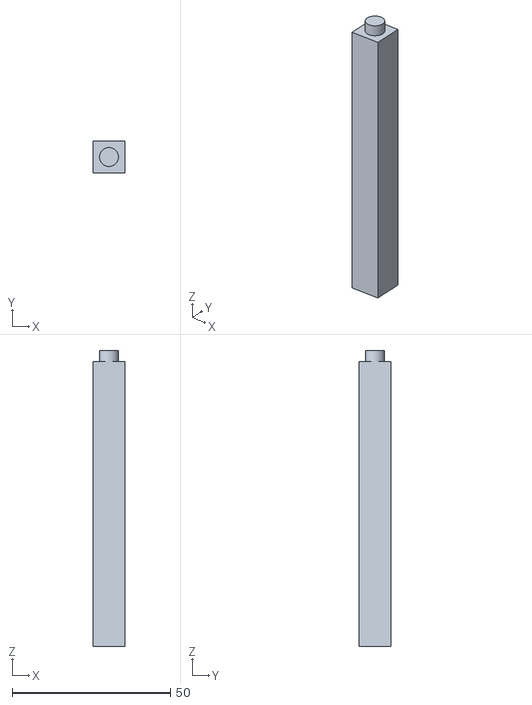
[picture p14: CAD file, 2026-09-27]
cad/table/Table_Leg.stl
10.0 x 10.0 x 93.5

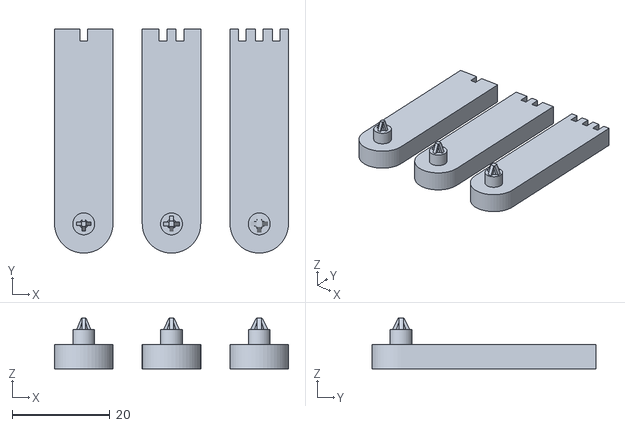
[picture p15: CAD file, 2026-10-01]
cad/driver_tip/Driver_Tips_x3.stl
48.0 x 46.0 x 10.4

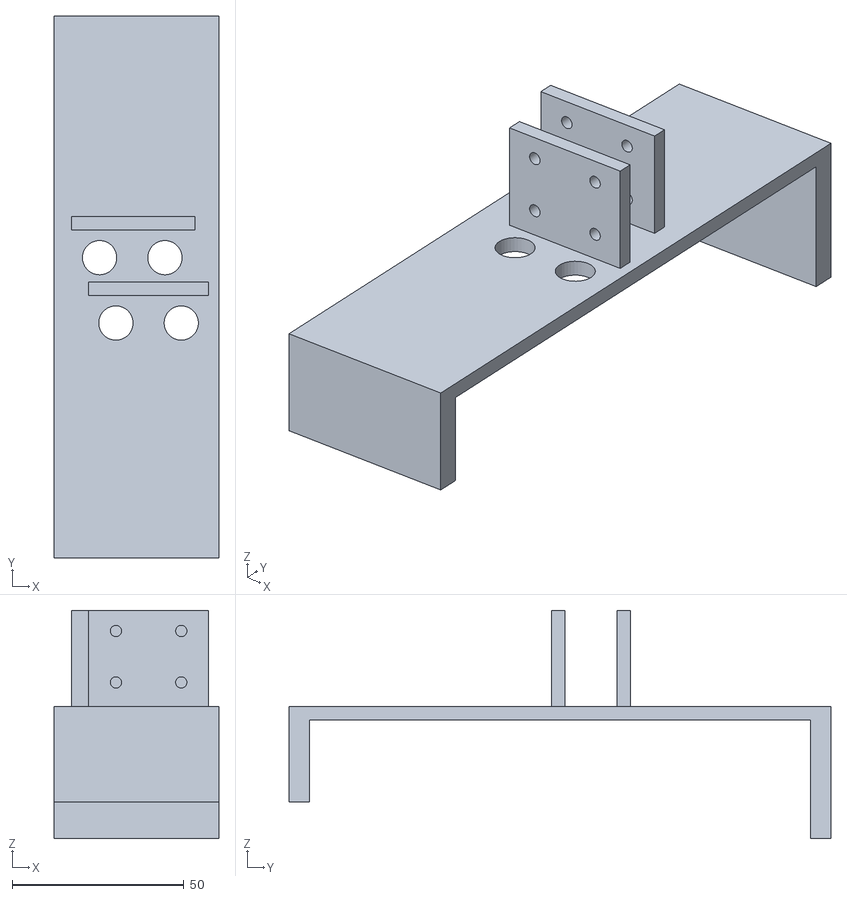
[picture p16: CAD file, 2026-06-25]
Prototype_2x2.stl
48.0 x 158.0 x 66.5

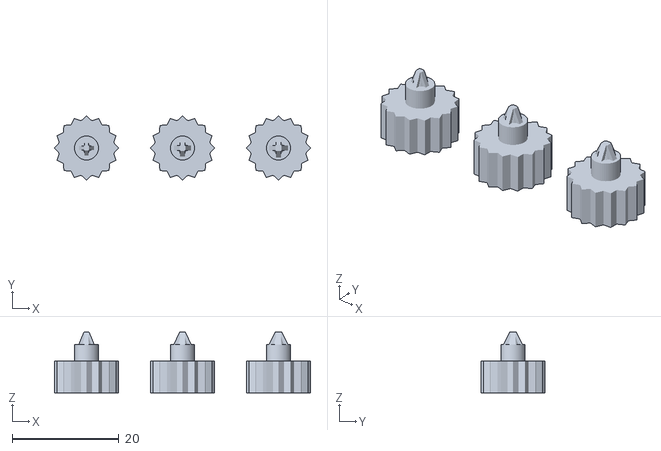
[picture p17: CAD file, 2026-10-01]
cad/driver_tip/tinyahhdriver.stl
48.0 x 12.0 x 11.4

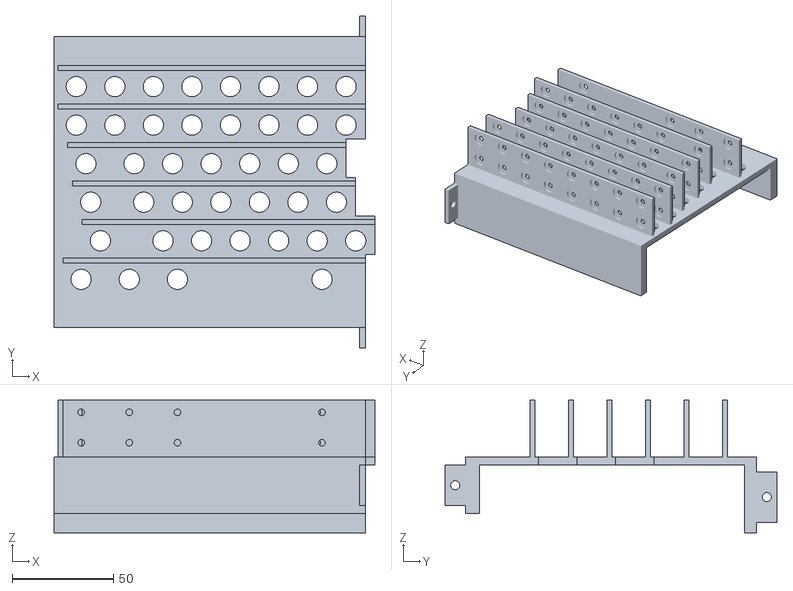
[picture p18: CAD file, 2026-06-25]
Air75_84Key_Plate_Left.stl
158.7 x 164.0 x 65.5

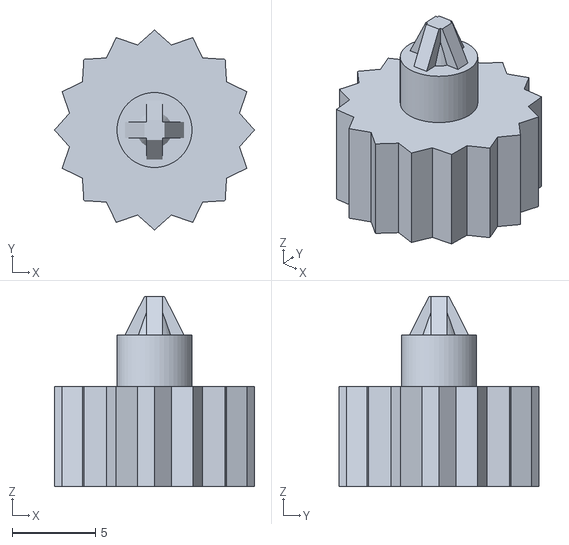
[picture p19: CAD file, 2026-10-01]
cad/driver_tip/Knob_D12_PH1_110.stl
12.0 x 12.0 x 11.4

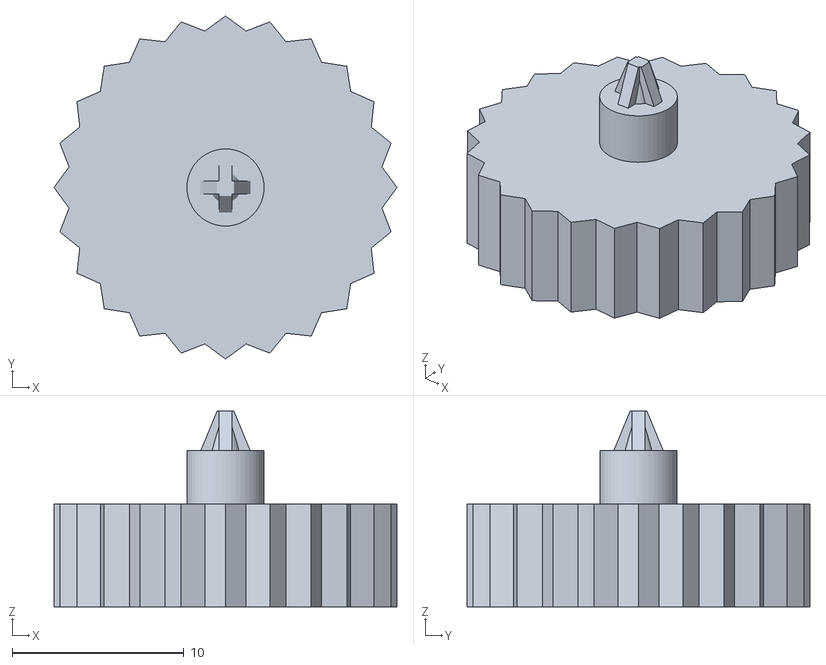
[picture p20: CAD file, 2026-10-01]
cad/driver_tip/Knob_D20_PH1_90.stl
20.0 x 20.0 x 11.4

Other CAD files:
2x2 Prototype VFINAL.stl
2x2 Prototype V3.stl
Air75_84Key_Plate_Right.stl
cad/driver_tip/Knob_D20_PH1_110.stl
Prototype2x2v3.stl
cad/driver_tip/Driver_PH1_100.stl
cad/driver_tip/Driver_PH1_110.stl
cad/driver_tip/Driver_PH1_90.stl
cad/driver_tip/Knob_D12_PH1_100.stl
cad/driver_tip/Knob_D12_PH1_90.stl
cad/driver_tip/Knob_D20_PH1_100.stl
cad/driver_tip/Knob_Drivers_x6.stl

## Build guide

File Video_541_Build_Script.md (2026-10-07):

# Video 2: "How I built it" (vertical, 1:30–1:45, voiceover + face)
**Drafted Oct 5, 2026.** Posts 3–5 days after Video 1 (the raw 618 run), ideally as a reply to a real "how does it work?" comment.
VO pace ≈ 150 wpm → ~230 words ≈ 1:35. Every VO line also goes on screen as captions (most viewers watch with the sound off).

## Script

| Time | Voiceover | Shot | Have it? |
|---|---|---|---|
| 0:00 | "This keyboard just typed 618 words per minute. Here's how I built it." | 2 s of the 618 run → result screen | ✅ phone clip |
| 0:05 | "Every key gets its own robot: a solenoid. Send it 12 volts and the plunger slams down on the key." | 240 fps slow-mo, one solenoid firing | 🎥 shoot |
| 0:13 | "84 of them, each exactly one key apart, tilted to match the keyboard. It took a test cell, a 2×2 prototype, and a full plate to get right." | Test cell → 2×2 → full plate (CAD renders + real parts) | ✅ renders / 🎥 parts |
| 0:25 | "An Arduino has 54 pins. I needed 84. So eleven shift registers turn a handful of wires into 88 outputs, and eleven driver chips switch the power." | Board close-up; `cell_x11_cascade.mp4` animation | ✅ animation |
| 0:37 | "I hand-soldered the first circuit. One of eleven took four hours. So I learned KiCad and designed my own circuit boards." | Perfboard cell #1 → KiCad screen recording → boards arriving | ✅ soldering clip / 🎥 KiCad screen rec |
| 0:49 | "Then 168 wires. I didn't label a single one, so I wrote a program that fires each solenoid and listens for which key shows up." | Wiring under the table → automap tool screen recording | 🎥 screen rec |
| 1:00 | "1 a.m. The solenoids start firing on their own. Then: *pop*." | Black screen or a dark shot, pop SFX | — |
| 1:05 | "A driver chip melted. New chip, plus a firmware fix that refreshes every chip 200 times a second." | Push in on socket B.U12 (the empty/replaced spot) + a fresh ULN2803A held up ("one of these"); optional red glow / smoke overlay | 🎥 shoot (melted chip was thrown away) |
| 1:13 | "2:37 a.m.: its first sentence." | "the quick brown fox…" typing on screen | ? (reshoot is easy) |
| 1:18 | "For speed, a script reads the words straight off Monkeytype and streams them over USB. Each key fires before the last one has even lifted." | Screen + keyboard; mt_reader panel | ✅ / 🎥 |
| 1:28 | "My goal was 320. It hit 340 with zero mistakes. Then I took the limiter off: 618, still zero mistakes." | 340 result → full run → 618 result | ✅ phone clips |
| 1:38 | "Next: all 84 keys." (or end on the result) | Face cam or plate wide shot | 🎥 |

## Pickups to shoot (one session, ~30 min)
1. 240 fps slow-mo: a single solenoid, then a row firing (`FAST` stream).
2. Socket B.U12 push-in + a spare ULN2803A in hand (the melted one was thrown away; check your phone for any photo from last night first).
3. Screen recordings: KiCad board, automap run, mt_reader panel + Monkeytype.
4. Wide shot under the table (wiring + paper-towel shim, for one honest laugh).
5. Face-cam lines: the opener and the closer at minimum.
6. Clean "quick brown fox" take if there's no footage of it.

## Edit notes
- Cut on solenoid clicks; keep real keyboard audio under the VO at about −18 dB.
- Make the pop the one moment with full silence before it.
- Show the 618 result twice: first as a tease (0:00), then as the payoff (1:30).
- Don't put "Part X" or "Day N" in the opening.

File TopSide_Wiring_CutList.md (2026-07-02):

# Top-Side Wire-Art — Cut List & Method (Driver Cell)

*Goal: clean, camera-ready wiring on the soldered perfboard, in the style of a breadboard "wire-art" build — jumpers routed on the **top (component) side** in crisp right angles. Plan, measure, shape, and cut every wire **before** the chips go in. This is cell #1 of 11; shape one set, then batch-repeat.*

Companion files: `Cell_TopSide_Routing.svg` (the visual target), `Driver_Cell_Perfboard_Layout.svg` (pin map), `Soldering_Plan.md` / `OneCell_595_ULN_Build_and_Fire_Guide.md` (the build itself).

> **Layout — ULN flipped 180° (notch RIGHT).** Inputs (IN) now sit on the ULN's **top** row facing the 595; outputs (OUT) on the **bottom** row facing the solenoids. This shortens the output drops and turns COM and ULN-GND into clean short taps. **AS-BUILT (July 2026): canonical wiring — Q0→IN1, Q1→IN2 … Q7→IN8** — so channel order stays sequential (FIRE N → OUT(N+1), nothing to fix in firmware). The trade: the flipped IN row runs right-to-left, so the 8 jumpers are a symmetric crossing fan of unique lengths (see §4), not a parallel batch. (The 595 is unchanged, notch LEFT.)

> **Spacing — chips moved 1 row apart (11-row gap).** Middle rails use **2 empty rows** between each chip and the nearest rail, and **2 between each rail**: 595 →2→ SH_CP →2→ ST_CP →2→ GND →2→ ULN. You had 10 rows between the chips; nudge to 11 (ULN down one, or 595 up one). The wider gap lengthens the logic bundle slightly (13 holes vs 9) — the trade for clean rail separation.

---

## 1. The one catch with top-side art on pad-per-hole perfboard

On a **breadboard**, every hole in a column is internally bused, so a jumper just plugs into any hole near a pin. On **pad-per-hole perfboard, every hole is isolated** — the electrical joint is made on the **bottom**, at each pad. A socket pin already fills its own hole, so a top-routed jumper cannot drop into the pin's hole.

**The fix (use this at every chip-pin end):** land the wire in the **free hole immediately next to the pin**, then on the bottom bend the stripped tail across and solder it to **both** its own pad **and** the pin's pad (a one-hole solder bridge made by the wire's own tail). Rail ends are easy — they drop straight into any free hole along the rail.

Because the wire body lies on top and only the ends dive through, wires **fly freely over chips, pins, and rails** — nothing mid-path needs a hole. That's exactly what makes the photo look good (wires arcing over the chips).

## 2. Split strategy — hero wires on top, housekeeping on the bottom

Not every wire should be on top. Put the **photogenic** wires up top and hide the **set-and-forget** ties underneath. The result looks intentional and is far easier to build.

**On top (the wire art):**
- The 8 logic jumpers Q→IN (the signature crossing fan)
- Signal taps: SH_CP, ST_CP, DS
- The 8 output drops OUT1–8 → solenoid landing holes
- Power taps: VCC→+5V, MR→+5V, 595 GND→GND, and — thanks to the flip — ULN GND→GND and COM→+12V (both now short, clean taps)

**On the bottom (kept off-camera):**
- OE→GND only — it's a 595 top-row pin needing GND below, the one link that still collides on top
- Both 0.1 µF decoupling caps and the reservoir cap
- The star-ground ties (PSU GND, Mega GND)

## 3. Measure / shape / cut — the method

**Pitch is everything.** Holes are 0.1″ = **2.54 mm** apart. Measure any run by **counting holes**, not with a ruler.

**Length formula (cut long, trim on fit):**

> cut length ≈ (hole span × 2.54 mm) + **15 mm** slack + **5 mm** for each chip it flies over

The 15 mm covers ~7.5 mm at each end for the strip + the 90° down-bend + insertion. Round up to the nearest 5 mm; you'll trim.

**Hole span = Manhattan distance:** horizontal holes + vertical holes between the two endpoints (right-angle path, no diagonals).

**Strip & bend:** strip ~**4 mm** at each end. Bend a crisp **90° down** right at the insulation edge so the bare leg drops into the hole and the insulated body lies flat on the board.

**Use the board as a bending jig.** Poke one end into its hole, lay the wire flat along the surface to the corner, and bend it down into the next hole. Bending *on the grid* guarantees pitch-perfect corners and identical parts — much cleaner than eyeballing.

**Batch identical wires.** Seven of the eight logic jumpers are the same length (see the list) — cut and shape all seven together for a uniform bundle. Uniformity is what reads as "clean" on camera.

**Color discipline (from your wiring map):** red = +5 V · orange = +12 V · black = GND · blue = DS · green = SH_CP · white = ST_CP · grey = signal (Q→IN, OUT→solenoid). One color per net, never reused.

---

## 4. Cut list — one cell

Columns C1–C9 = board columns left→right. The 595 is notch-**LEFT**; the ULN is flipped notch-**RIGHT**, so its IN row is on top. "Holes" = Manhattan span between endpoints. Cut = suggested length to cut, then trim. (Q→IN pairs below are **canonical, as-built**: a symmetric crossing fan — Q0–Q4 cross right, Q5–Q7 cross left. Batch the length-pairs: 2×50, 2×55, 2×60.)

### On-board, top side

| # | Wire | Color | From | To | Holes | Cut | Bend |
|---|---|---|---|-----|:----:|:---:|---|
| 1 | Q0→IN1 | grey | 595 pin 15 (top row) | ULN pin 1 | 22 | **70 mm** | L (the long one — flies over the 595, over 7 →) |
| 2 | Q1→IN2 | grey | 595 pin 1 | ULN pin 2 | 19 | **65 mm** | L (down, over 7 →) |
| 3 | Q2→IN3 | grey | 595 pin 2 | ULN pin 3 | 17 | **60 mm** | L (down, over 5 →) |
| 4 | Q3→IN4 | grey | 595 pin 3 | ULN pin 4 | 15 | **55 mm** | L (down, over 3 →) |
| 5 | Q4→IN5 | grey | 595 pin 4 | ULN pin 5 | 13 | **50 mm** | L (down, over 1 →) |
| 6 | Q5→IN6 | grey | 595 pin 5 | ULN pin 6 | 13 | **50 mm** | L (down, over 1 ←) |
| 7 | Q6→IN7 | grey | 595 pin 6 | ULN pin 7 | 15 | **55 mm** | L (down, over 3 ←) |
| 8 | Q7→IN8 | grey | 595 pin 7 | ULN pin 8 | 17 | **60 mm** | L (down, over 5 ←) |
| 9 | VCC→+5V | red | 595 pin 16 | +5V rail | 2 | 20 mm | I (straight up) |
| 10 | MR→+5V | red | 595 pin 10 | +5V rail | 2 | 20 mm | I |
| 11 | 595 GND→GND | black | 595 pin 8 | GND spine | 9 | 40 mm | I (crosses SH, ST) |
| 12 | SH_CP tap | green | 595 pin 11 | SH_CP rail | 6 | 30 mm | I (flies over chip) |
| 13 | ST_CP tap | white | 595 pin 12 | ST_CP rail | 9 | 40 mm | I (crosses SH) |
| 14 | **ULN GND→GND** | black | ULN pin 9 (now top-left) | GND spine | 3 | 25 mm | I (short tap ↑) |
| 15 | **COM→+12V** | orange | ULN pin 10 (now bottom-left) | +12V rail | 2 | 20 mm | I (short tap ↓) |
| 16–23 | **OUT1→…OUT8 → landing holes** (8) | grey | ULN pins 18→11 (bottom row) | solenoid landing holes | 2 | 20 mm ×8 | I (straight drop) |

### On-board, bottom side (short link — no need to pre-shape)

| Wire | Color | From | To | Note |
|---|---|---|-----|---|
| OE→GND | black | 595 pin 13 | GND rail | 595 top-row pin, GND is below it — one short link underneath |

### Flying leads — measure in place, don't pre-cut

| Lead | Color | Length | When |
|---|---|---|---|
| DS → Mega D11 | blue | ~150–200 mm | cell #1 only |
| Q7′ → next cell's DS | blue | ~one cell pitch (~45 mm) | cells 1–10 (cascade) |
| SH_CP rail → Mega D12 | green | ~150–200 mm | once per board |
| ST_CP rail → Mega D13 | white | ~150–200 mm | once per board |
| Mega GND → GND rail | black | ~150 mm | once per board (star point) |
| Solenoid runs (OUT landing hole→coil low side; coil high side→+12 V bus) | grey / orange | to the solenoid | 22 AWG **stranded**, off-board |

### Buses (bare wire, laid continuous across all 11 cells)

| Rail | Color | Build |
|---|---|---|
| +5V | red | single 22 AWG solid, soldered every hole |
| SH_CP | green | single 22 AWG solid |
| ST_CP | white | single 22 AWG solid |
| **GND spine** | black | **2× 22 AWG solid in parallel + solder bead** (fat) |
| **+12V** | orange | **2× 22 AWG solid in parallel + solder bead** (fat) |

### Components (place, don't cut)

- 0.1 µF ceramic ×2 — across 595 pins 16↔8 and ULN pins 10↔9, legs short, bottom side.
- 470 µF electrolytic (single cell) — + leg → +12 V, stripe → GND, near the ULN.

---

## 5. Work order

1. **Shape & cut** the whole cell from this list (batch the fan's length-pairs: 2×50, 2×55, 2×60). Lay each set out on tape in order — you're pre-building the whole cell before any heat.
2. **Dry-fit** the shaped wires on the board (chips still out) to confirm every length reaches. Trim.
3. **Solder the sockets** — 595 notch **LEFT**, ULN notch **RIGHT** (flipped). Tack 2 corners, check flat, finish.
4. **Lay the 5 rails** (buses). Keep +5 V and +12 V apart; GND and +12 V get the doubled-wire + solder-bead treatment.
5. **Place the top bundle**: logic jumpers first, in **canonical order (Q0→IN1 … Q7→IN8), longest-first** so the fan's crossings layer consistently; then the signal and power taps. Ends into the adjacent free holes, tails soldered across to the pins underneath.
6. **Bottom housekeeping**: OE→GND, both 0.1 µF caps, reservoir cap. (COM and ULN-GND are now top taps.)
7. **Outputs**: OUT1–8 drop straight down to their solenoid landing holes.
8. **Flying leads** last: DS/clock/latch/GND to the Mega, cascade to the next cell.
9. **Cold-test** per `OneCell_595_ULN_Build_and_Fire_Guide.md` §4 → 5 V only → 12 V last.

Then repeat cells 2–11: rails just extend right, and the 8-jumper fan set is identical every time.

---

## 6. For the camera

Uniform wire height, identical bends, tight parallel bundles, and strict color coding are what make it read as "wire art." Shoot the top bundle before you flip the board for the bottom housekeeping. **Milestone:** once the cell fires clean, commit a photo of the finished top-side routing + your final `PULSE` value to GitHub.

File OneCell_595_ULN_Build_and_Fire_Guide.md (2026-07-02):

# One-Cell Driver Test — Build & Fire Guide

**Scope:** build and fire a single driver cell — **one 74HC595 + one ULN2803A driving 4 solenoids** — on real perfboard, from bare board to four clicks. This is **cell #1 of Board A**, so build it as the real thing: the rails you lay here will later extend rightward to cells 2–4.

**The chain:** Arduino Mega → 74HC595 (shift register, turns 3 Mega pins into 8 outputs) → ULN2803A (driver, switches the 12 V solenoid current) → 4 solenoids.

**Milestone:** this is your "first fire from a soldered board." Film it; commit a photo + any pulse tweak to GitHub when it works.

**Realistic time:** 4–6 h for a first solder job. It splits cleanly: Session 1 = all soldering (§3) + cold test (§4); Session 2 = power-up (§5) + fire (§6). Don't rush — a hurried cold joint costs more to find later than it saves now.

> Convention: **595 pin N** and **ULN pin N** always mean the chip's pin number. You solder to the matching **socket** pin. Chips stay OUT of the sockets until §5.

---

## 0. Parts, tools, safety

### 0.1 Parts for this one cell

- [ ] 1× 74HC595 shift register (DIP-16)
- [ ] 1× ULN2803A Darlington driver (DIP-18)
- [ ] 1× 16-pin DIP socket  ·  1× 18-pin DIP socket
- [ ] 2× 0.1 µF ceramic capacitor (decoupling — non-polarized)
- [ ] 1× 4700 µF 25 V electrolytic capacitor (reservoir — polarized) *(you own 2; use one)*
- [ ] 22 AWG **solid** hookup wire for rails + jumpers, in net colors (red/orange/black/blue/green/white)
- [ ] 18 AWG silicone wire (red/black) for the 12 V PSU feed
- [ ] 22 AWG **stranded** wire for the 4 solenoid runs (off-board — flexes without cracking)
- [ ] 4× prototype solenoids (the 5 N fast-ship kit)
- [ ] Your perfboard (Board A), pad-per-hole, ~33 rows
- [ ] 1× 8-pin header (optional, for the outputs — or solder solenoid wires straight to the OUT pads)
- [ ] Arduino Mega + USB cable  ·  12 V PSU (BOSYTRO) + IEC cord

### 0.2 Tools

- [ ] Soldering iron + stand, 60/40 leaded solder, flux pen, brass wool
- [ ] Solder wick **and/or** solder sucker (for bridges / rework)
- [ ] **Multimeter with continuity (beep) mode** — used heavily in §4
- [ ] Wire strippers, flush cutters, needle-nose pliers, tweezers
- [ ] Safety glasses, a fan or open window, a 30-min iron timer
- [ ] An accessible switch on the 12 V (your "kill switch")

### 0.3 Safety — non-negotiable

- **Glasses on.** Iron back in the stand the instant it leaves your hand.
- **Ventilate** — fan pushing flux fumes away or a window open. Don't lean into the smoke.
- **Leaded solder:** wash hands before eating; don't eat at the bench.
- **Never solder a powered board.** Unplug the 12 V before any wiring change.
- **5 V and 12 V never touch.** Only the grounds tie, at one star point. (This is the one that smokes chips.)

---

## 1. Soldering technique (the 60-second version)

You skipped the practice stage, so these first joints *are* your practice — go slow on the first dozen.

**Tin the tip:** at temp (~325–340 °C), melt a little solder on the tip and wipe on brass wool. Re-tin whenever it looks dull. A bright wetted tip transfers heat; a dull one doesn't.

**The five-count joint:**

1. Press the iron against **both** the copper pad **and** the pin at once.
2. Count ~1–2 s (heat the joint).
3. Feed solder into the **joint**, on the side away from the iron — not onto the tip.
4. ~1 s, pull the solder away.
5. Pull the iron away. **Don't move it** for 2–3 s while it freezes.

**Reading the joint:**

| Looks like | Verdict | Fix |
|---|---|---|
| Shiny little volcano, hugs pad + pin | Good | — |
| Dull, grainy, lumpy | Cold joint | Reheat, add a touch of fresh solder |
| Ball sitting on top, not stuck | No wetting | Reheat the **pad** longer, add flux |
| Solder linking two pads you didn't want | Bridge | Flux + drag wick across it |
| Pad peeling off the board | Overheated | Stop; jumper to the next pad to recover |

---

## 2. Plan it on paper first (your board)

Pad-per-hole means **nothing is connected until you solder it** — so a sketch keeps you from trapping yourself. You measured ~33 rows; here's the cell stacked top-to-bottom (matches your 7 / 4 / 10 / 4 / 8 placement):

```
row 1–6    top margin            ← +5V rail lives here (row ~6, just above the 595)
row 6      ───── +5V rail (red)
row 8–11   [ 74HC595  DIP-16 ]   ← top pins row 8, bottom pins row 11; NOTCH LEFT = pin 1
row ~14    ───── SH_CP rail (green)
row ~16    ───── ST_CP rail (white)
row ~19    ───── GND rail (black) ★ spine
row 22–25  [ ULN2803A DIP-18 ]   ← top pins row 22, bottom pins row 25; NOTCH LEFT = pin 1
row ~27    ═════ +12V rail (orange, heavier)
row ~29    [ 8-pin OUTPUT header ]  → solenoids
row 30–33  bottom margin         ← leave clear for output wires to exit
```

- Both chips: **long axis horizontal, notch/pin-1 to the LEFT**, top pin-row facing the +5 V rail.
- A DIP's two pin-rows sit **3 holes (0.3″) apart** — that's why the 595 lands on rows 8 & 11, the ULN on 22 & 25.
- This vertical layout **repeats for cells 2–4** later; measure it once here and match it.

---

## 3. Build — exact order (chips stay OUT)

Work top-to-bottom, rails before the board gets crowded. **Wire colors** (adopt and never reuse): red = +5 V, orange = +12 V, black = GND, blue = DS, green = SH_CP, white = ST_CP, grey = signal (Q→IN, OUT→solenoid).

### Step 1 — sockets

Drop the **DIP-16** and **DIP-18** sockets in from the top, notch/pin-1 LEFT, both the same way. **Tack two diagonal corners** of each, check it sits **dead flat**, then solder **every** pin (all 16, all 18). The chips themselves go in last (§5) — never solder a chip.

### Step 2 — the five rails (bare 22 AWG bus wire)

Lay each as a straight bare wire soldered down a row (§2 positions). For this single cell they're short; they'll extend right later.

- [ ] **+5 V** (red) — top, ~row 6
- [ ] **SH_CP** (green) — ~row 14
- [ ] **ST_CP** (white) — ~row 16
- [ ] **GND** (black, the spine ★) — ~row 19 — make this generous
- [ ] **+12 V** (orange, heavier) — ~row 27 — keep it well away from +5 V

### Step 3 — 595 power + decoupling cap

| 595 pin | Name | Connect to |
|--:|---|---|
| 16 | VCC | **+5 V** rail |
| 10 | MR̅ | **+5 V** rail (don't reset) |
| 8 | GND | **GND** rail |
| 13 | OE̅ | **GND** rail (outputs always enabled) |

- [ ] **0.1 µF** across **pin 16 ↔ pin 8**, legs short. (Non-polarized — either way round. If the pins aren't on adjacent holes, put the cap on the two nearest empty holes and run two short jumpers. *Short is the whole point.*)

### Step 4 — ULN power + decoupling cap

| ULN pin | Name | Connect to |
|--:|---|---|
| 9 | GND | **GND** rail |
| 10 | COM | **+12 V** rail — **enables the internal flyback diodes; never skip** |

- [ ] **0.1 µF** across **pin 10 ↔ pin 9**, legs short.

### Step 5 — logic jumpers, 595 → ULN (8 insulated jumpers)

Q0–Q7 map one-to-one to IN1–IN8:

| 595 output (pin) | → | ULN input (pin) |
|---|---|---|
| Q0 (15) | → | IN1 (1) |
| Q1 (1) | → | IN2 (2) |
| Q2 (2) | → | IN3 (3) |
| Q3 (3) | → | IN4 (4) |
| Q4 (4) | → | IN5 (5) |
| Q5 (5) | → | IN6 (6) |
| Q6 (6) | → | IN7 (7) |
| Q7 (7) | → | IN8 (8) |

*(595 pin 9 = Q7′ is left open on a single cell — it's the cascade out for the next chip.)*

### Step 6 — control leads to the Mega + power feeds

| From | → To | Color |
|---|---|---|
| 595 pin 14 (DS) | Mega **D11** | blue |
| 595 pin 11 (SH_CP) | Mega **D12** | green |
| 595 pin 12 (ST_CP) | Mega **D13** | white |
| Mega **GND** | GND rail (star point) | black |
| Mega **5 V** pin | +5 V rail | red |

*(The Mega is powered by USB from your laptop; its 5 V pin feeds the +5 V rail. Do NOT also feed +5 V from the 12 V PSU.)*

### Step 7 — outputs + solenoids

ULN OUT1–OUT8 are pins **18 → 11** (outputs run in reverse of inputs). Land them on the 8-pin header (or wire directly). For the 4 prototype solenoids use channels 0–3:

| Channel | ULN OUT (pin) | Solenoid |
|---|---|---|
| 0 | OUT1 (18) | solenoid 1 low side |
| 1 | OUT2 (17) | solenoid 2 low side |
| 2 | OUT3 (16) | solenoid 3 low side |
| 3 | OUT4 (15) | solenoid 4 low side |

- [ ] Each solenoid: **one lead → its OUT/header pin**, **other lead → +12 V rail** (use 22 AWG stranded for these off-board runs).
- [ ] Bring the **12 V feed** in with 18 AWG silicone: **PSU +12 V → +12 V rail**.

### Step 8 — reservoir cap (POLARITY MATTERS)

- [ ] **4700 µF 25 V** across **+12 V ↔ GND**, placed **near the ULN**.
- **+ leg (longer) → +12 V rail (orange).**
- **− leg (stripe/arrow on the can) → GND rail (black).**
- Reverse it and it overheats and can **burst** (loud pop, hot electrolyte). Double-check now, and again before first power. 25 V rating on a 12 V rail is correct.

### Step 9 — star ground

- [ ] **PSU GND → GND rail** at one point (Mega GND already tied in Step 6). All grounds meet at this one spot — that's the star. Sloppy grounding is the #1 "works on breadboard, glitches when soldered" cause.

---

## 4. Cold continuity test — multimeter, NOTHING powered, chips still OUT

This is the step that saves chips. Unplug everything. Set the meter to **continuity (the beep / ♪ symbol)**: touch the two probes together first to hear the beep so you know it works. Then check, in order.

### 4.1 Shorts that must NOT exist — expect **silence / OL (open)**

| Probe A | Probe B | Want |
|---|---|---|
| +5 V rail | +12 V rail | **no beep** |
| +5 V rail | GND rail | **no beep** |
| +12 V rail | GND rail | **no beep** |
| any output/header pin | its neighbor pin | **no beep** |

A beep here = a bridge or a misroute. Find and clear it (flux + wick) before going on. **+5 V ↔ +12 V must be open** — meter it twice.

### 4.2 Connections that MUST exist — expect **beep**

| Probe A | Probe B | Want |
|---|---|---|
| 595 pin 16 | +5 V rail | beep |
| 595 pin 10 | +5 V rail | beep |
| 595 pin 8 | GND rail | beep |
| 595 pin 13 | GND rail | beep |
| ULN pin 10 | +12 V rail | beep |
| ULN pin 9 | GND rail | beep |
| GND rail | Mega GND | beep |
| GND rail | PSU GND | beep |
| 595 pin 14 | Mega D11 | beep |
| 595 pin 11 | Mega D12 | beep |
| 595 pin 12 | Mega D13 | beep |
| each 595 Q (15,1–7) | its ULN IN (1–8) | beep (all 8) |
| each ULN OUT (18,17,16,15) | its solenoid low-side lead | beep |

### 4.3 Capacitor polarity — eyeball, don't meter

- [ ] Reservoir **4700 µF**: + (long leg) on **+12 V**, stripe on **GND**. Look twice.
- [ ] Both **0.1 µF** sit right across their chip's power pins (595 16↔8, ULN 10↔9), legs short.

**Pass criteria:** every "no beep" is silent, every "beep" beeps, polarity confirmed. Only then apply power.

---

## 5. Power-up — exact sequence (do not reorder)

### 5.1 Seat the chips

With power **off**, press the **74HC595** and **ULN2803A** into their sockets. **Notch/pin-1 must match the socket** (and your §2 sketch). Pins often splay — rock each chip on a flat surface to bend them in slightly so they seat without bending under.

### 5.2 5 V logic only — no 12 V yet

1. Leave the 12 V PSU **off/disconnected**.
2. Power the Mega over USB (this drives the +5 V rail).
3. **Feel both chips.** Anything warm, or any smell → **cut power immediately** and re-check §4. Cold chips = good.
4. Flash `firmware/keyboard_v0/keyboard_v0.ino`. Open Serial Monitor at **115200 baud, line ending = Newline**. You should see: `keyboard_v0 ready (pulse 40 ms)…`.
5. Sanity-check the logic with no solenoids: type `FIRE 0`. The board can't click yet (no 12 V), but the meter on **ULN pin 1 (IN1)** should blip, or probe **595 Q0 (pin 15)**. If outputs respond, your shift register + wiring are alive.

### 5.3 Add 12 V last

1. PSU **off**. Connect the 12 V feed (+12 V → +12 V rail, GND → GND star). Connect your 4 solenoids.
2. **Hand near the kill switch**, then switch the PSU on.
3. Quiet board, no smell, no heat = good. Any pop/smell/heat → kill instantly.

---

## 6. Fire the solenoids

With `keyboard_v0` running and 12 V live (Serial Monitor, 115200, Newline):

```
FIRE 0      ← fires channel 0 at the default pulse (40 ms)
FIRE 1
FIRE 2
FIRE 3
```

Each returns `OK FIRE <ch> <ms>` and gives one crisp click. Or sweep all four at once:

```
BURST 4     ← fires channels 0–3 in sequence (100 ms gap)
```

If a fire ever hangs on: `ALLOFF` forces every channel low.

**Pass criteria:** 4 clicks in order, plungers fully retract between fires, **no buzzing, no missed clicks**. That's the milestone.

### 6.1 Tune the pulse

- `PULSE 30` sets the default to 30 ms; `PULSE` alone reports the current value. Or override per-shot: `FIRE 0 30`.
- Start at **40 ms**, try **30 ms** and **50 ms**, and listen. Shorter = less heat. Your 2×2 prototype ran well as low as **~22 ms**.
- Guardrails baked into the firmware: pulses are clamped to **200 ms max**, with a forced **20 ms gap** between fires.

### 6.2 Optional — measurements while it's live (feeds your Week-3 CAD)

While the cell is firing, capture: plunger **rest extension** (mm), **force** at 30/50/80 ms (push against a tared kitchen scale), and **body temperature** after ~200 fires at 50 ms / 100 ms gap (touch test — flag if uncomfortably hot).

---

## 7. Troubleshooting

| Symptom | Likely cause | Fix |
|---|---|---|
| No `OK` in Serial Monitor | Wrong baud/port, or sketch not flashed | 115200 + Newline; reselect port; re-flash |
| `OK FIRE` but **no click** | No 12 V, or **COM (pin 10) not on +12 V**, or cold output joint | Confirm 12 V on; reflow COM→+12 V; check solenoid leads |
| **One** channel dead | That Q→IN jumper, or that OUT joint / solenoid | Continuity-test that single path (§4.2) |
| **All** dead, but outputs toggle on the meter | 12 V missing, or COM not tied | Check the 12 V feed and COM→+12 V |
| Weak / buzzing click | Pulse too short, low 12 V, or sagging rail | Raise pulse; verify 12 V; confirm reservoir cap present + correct polarity |
| Chip **hot** or any **smell** | Short (5 V↔12 V), reversed reservoir cap, or COM miswired | **Kill power.** Re-run §4 shorts + cap polarity |
| Random / glitchy fires | Missing 0.1 µF decoupling, sloppy ground, or a bridge | Add/secure both 0.1 µF; verify single star ground; wick any bridge |
| Plunger stuck extended at rest | Solenoid orientation / mechanical, not the driver | Energize behavior: the ball-tip extends on fire, retracts at rest — re-check mounting |

---

## 8. The 5 gotchas (tape above the bench)

1. **ULN COM (pin 10) → +12 V.** No flyback = a dead driver on the first solenoid.
2. **5 V and 12 V never touch.** Only the grounds tie, at one star point.
3. **Socket every IC.** Never solder the chip itself.
4. **0.1 µF across every chip's power pins** (595 16↔8, ULN 10↔9), legs short.
5. **Reservoir polarity** (+ to 12 V, stripe to GND) and **test cold → 5 V-only → 12 V last.**

---

## 9. Pin reference

### 74HC595 (DIP-16)

| Pin | Name | Connect to |
|--:|---|---|
| 1 | Q1 | ULN IN2 (2) |
| 2 | Q2 | ULN IN3 (3) |
| 3 | Q3 | ULN IN4 (4) |
| 4 | Q4 | ULN IN5 (5) |
| 5 | Q5 | ULN IN6 (6) |
| 6 | Q6 | ULN IN7 (7) |
| 7 | Q7 | ULN IN8 (8) |
| 8 | GND | GND rail |
| 9 | Q7′ | open (cascade out — unused on one cell) |
| 10 | MR̅ | +5 V rail |
| 11 | SH_CP | Mega D12 (green) |
| 12 | ST_CP | Mega D13 (white) |
| 13 | OE̅ | GND rail |
| 14 | DS | Mega D11 (blue) |
| 15 | Q0 | ULN IN1 (1) |
| 16 | VCC | +5 V rail (+ 0.1 µF to GND) |

### ULN2803A (DIP-18)

| Pin | Name | Connect to |
|--:|---|---|
| 1–8 | IN1–IN8 | 595 Q0–Q7 |
| 9 | GND | GND rail (+ PSU GND) |
| 10 | COM | +12 V rail (+ 0.1 µF to GND) |
| 11 | OUT8 | solenoid 8 low side |
| 12 | OUT7 | solenoid 7 low side |
| 13 | OUT6 | solenoid 6 low side |
| 14 | OUT5 | solenoid 5 low side |
| 15 | OUT4 | solenoid 4 (ch 3) low side |
| 16 | OUT3 | solenoid 3 (ch 2) low side |
| 17 | OUT2 | solenoid 2 (ch 1) low side |
| 18 | OUT1 | solenoid 1 (ch 0) low side |

*Each solenoid's other lead → +12 V rail.*

### Serial command cheat-sheet (`keyboard_v0`, 115200, Newline)

| Command | Does |
|---|---|
| `FIRE <ch> [ms]` | fire one channel 0–7 (`FIRE 0` = default pulse; `FIRE 0 30` = 30 ms) |
| `BURST [n [pulse [gap]]]` | fire channels 0…n-1 in sequence (default `BURST 4`) |
| `PULSE [ms]` | set / report the default pulse |
| `ALLOFF` | force every channel low (use if a fire hangs) |
| `MAP`, `TYPE`, `LEAD` | key-mapping + typing (not needed for the fire test) |

---

## 10. Done

Four crisp clicks from a soldered cell = **Stage 2 complete.** Film it. Commit the working-cell photo + any `PULSE` value you settled on to GitHub. Then repeat this exact cell for #2–#4 on Board A (rails just extend right), continuity-testing each column as you finish it.

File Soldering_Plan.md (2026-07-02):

# Soldering & Assembly Guide — Physical AI Agent Driver Board

*Comprehensive build guide for a **first-time solderer**, focused on the part that's actually hard: **the connections** — how to lay power rails, route every wire, and land the capacitors on perfboard. Source of truth for the netlist is `firmware/keyboard_v0/keyboard_v0.ino`, `firmware/README.md`, and `Driver_Board_Wiring_Map.svg`. This doc turns that netlist into physical, hole-by-hole actions.*

**The chain:** Arduino Mega → 11× 74HC595 shift registers → 11× ULN2803A drivers → 84 solenoids (88 channels, 4 spare). The whole board is **one cell repeated 11×**: build one perfect cell (Stage 2), then it's stamina (Stage 3).

---

## Table of contents

1. [Safety](#1-safety)
2. [Soldering technique — the short version](#2-soldering-technique--the-short-version)
3. [Perfboard, explained](#3-perfboard-explained)
4. [The three ways to make a connection](#4-the-three-ways-to-make-a-connection)
5. [Wire: gauge + color code](#5-wire-gauge--color-code)
6. [Power rails / bus bars — the core skill](#6-power-rails--bus-bars--the-core-skill)
7. [Capacitors — decoupling + reservoir](#7-capacitors--decoupling--reservoir)
8. [Stage 1 — practice](#8-stage-1--practice)
9. [Stage 2 — wire ONE cell + fire the 2×2](#9-stage-2--wire-one-cell--fire-the-22)
10. [Stage 3 — the full 88-channel board](#10-stage-3--the-full-88-channel-board)
11. [First power-up + continuity testing](#11-first-power-up--continuity-testing)
12. [The 5 gotchas](#12-the-5-gotchas-that-kill-driver-boards)
13. [Pin reference](#13-pin-reference)
14. [Pacing + GitHub](#14-pacing--github)

---

## 1. Safety

Review this every session for the first month.

- **Glasses on.** Iron back in its stand the instant it leaves your hand. 30-min timer.
- **Ventilate** — a fan pushing flux fumes away, or an open window. Don't lean into the smoke.
- **Leaded solder** → wash hands before eating; don't eat at the bench.
- **Never solder a powered board.** Unplug the 12 V PSU before *any* wiring change — those terminals can weld a screwdriver.
- **5 V and 12 V never touch.** Only the grounds tie, at one point. (This is electrical, not a burn — but it's the one that smokes chips.)

---

## 2. Soldering technique — the short version

You said first time, so the muscle-memory matters more than theory. Two rules: **a clean tinned tip, and you heat the joint, not the solder.**

**Tin the tip:** as soon as the iron hits temp (~325–340 °C for 60/40 leaded), melt a bit of solder onto the tip and wipe on brass wool. Re-tin whenever it looks dull/grey. A bright, wetted tip transfers heat; a dull one doesn't.

**The five-count joint:**

1. Press the iron against **both** the copper pad **and** the component lead at once.
2. Count ~1–2 s (let the joint heat).
3. Feed solder into the **joint**, on the side away from the iron — not onto the tip.
4. ~1 s, pull the solder away.
5. Pull the iron away. **Don't move it** for 2–3 s while it freezes.

**Reading the result:**

| Looks like | Verdict | Fix |
|---|---|---|
| Shiny little volcano, hugs pad + lead | Good | — |
| Dull, grainy, lumpy | Cold joint (moved or too little heat) | Reheat, add a touch of fresh solder |
| Ball sitting on top, not stuck to pad | No wetting (didn't heat the pad) | Reheat the pad longer, add flux |
| Solder linking two pads you didn't want joined | Bridge | Flux + drag wick across it |
| Pad lifted off the board | Overheated / too long | Avoid — use a jumper to the next pad to recover |

Flux pen helps any joint wet faster. Keep the wick handy — bridges are normal, clearing them is a 5-second move once you've practiced it (Stage 1).

---

## 3. Perfboard, explained

Your BOM perfboard is **single-sided, through-hole** (10×15 cm). Two flavors exist — know which you have:

- **Pad-per-hole** (most common, almost certainly yours): every hole has its own isolated copper ring on the bottom. **Nothing is connected** until you connect it. Maximum freedom, you make every link by hand. *This guide assumes this.*
- **Stripboard / Veroboard:** copper runs in continuous strips across whole rows. You *cut* a strip (with a drill bit or knife) to break it where you don't want a connection. If yours is strips, the rails are half-built for you — but you must cut gaps under each IC so opposite pins aren't shorted. Tell me if it's strips and I'll adapt the steps.

**Orientation:** components sit on the **top** (plain) side, legs poke through, you solder on the **bottom** (copper) side and route most jumpers there. The hole grid is **0.1″ (2.54 mm)** pitch — the exact spacing of DIP IC pins, so sockets drop straight in.

**Read the board like graph paper.** Pick a corner as (col 1, row 1). Plan on paper in those coordinates before you solder anything — "595 #1 socket spans cols 3–4, rows 5–12" — so you don't run out of room or trap yourself. A pencil sketch saves an hour of desoldering.

---

## 4. The three ways to make a connection

Every link on the board is one of these:

1. **Bent lead.** A component's own trimmed leg, bent over on the solder side to reach an adjacent pad, then soldered. Good for a cap spanning two neighboring pins. Free, but only reaches ~1–3 holes.
2. **Solder bridge.** Deliberately blob solder across 2–3 *adjacent* pads to join them. Useful for short rail segments. **Use sparingly** — as a beginner you'll make accidental ones, so don't rely on intentional ones over distance.
3. **Jumper wire** (your workhorse). A cut piece of 22 AWG solid wire, stripped both ends, routed on the solder side from pad A to pad B, soldered at each end. **Insulated** for any run that crosses other connections; **bare/tinned** for buses (next section). 90% of your connections are jumpers.

**Beginner rule of thumb:** sockets and component legs go through from the top; everything else is a **jumper on the bottom**. Resist long solder-bridge trails — they look fast and fail slow.

How to make a clean jumper:
- Cut to length with ~5 mm extra. Strip ~3 mm each end. Tin both ends (melt a little solder into the strands/wire so it's pre-wetted).
- Hold one end on the target pad, touch iron, the pre-tinned wire fuses in ~1 s. Repeat the other end.
- Route flat against the board; don't leave loops that can snag or short.

---

## 5. Wire: gauge + color code

You have three wire types — each has a job:

| Wire | Use it for | Why |
|---|---|---|
| **22 AWG solid** (multi-color) | On-board jumpers + the +5 V / GND / signal rails | Solid holds its shape in holes and routes neatly |
| **18 AWG silicone stranded** (red/black) | The 12 V feed PSU→board, and board GND→PSU | Carries the big current; flexible |
| **22 AWG stranded** (multi-color) | Board output header → each solenoid (off-board runs) | Flexes without fatiguing; solid-core would crack at the solder joint over time |

**Color code** — adopt the one already on your wiring map so the board matches the drawing:

- **Red** = +5 V logic
- **Orange/Yellow** = +12 V power
- **Black** = GND (common)
- **Blue** = DS (serial data)
- **Green** = SH_CP (shift clock)
- **White** = ST_CP (latch)

Pick a color *per net* and never reuse it for something else. On a 260-joint board, color discipline is the difference between a 10-minute fault hunt and a 2-hour one.

---

## 6. Power rails / bus bars — the core skill

A **rail** (bus) is one continuous conductor that many chips tap for the same net. You will build **three power rails** (+5 V, GND, +12 V) plus **two signal rails** (SH_CP, ST_CP). Get this right and the rest is just taps.

### How to physically lay a rail

**Method — bare bus wire along a row** (do this):

1. Cut a length of **22 AWG solid** wire spanning the full width you need (for the full board, edge to edge). Strip **all** the insulation off — you want bare wire. (Or use bare tinned bus wire if your kit has it.)
2. Lay it flat on the **solder side**, running straight along **one row of holes**.
3. Tack it down: solder it to the pad at the **first** hole, pull it taut and straight, solder the **last** hole, then solder **every** hole (or at minimum every hole you'll tap + every 3rd hole for mechanical hold). Now that entire row is one continuous conductor.
4. A component or jumper "joins the rail" by soldering to **any pad along that row.**

That's it — a rail is just a wire soldered down a row, with everything for that net soldered onto it.

### Where each rail goes (floor plan)

Lay them out so the 5 V side and 12 V side are physically separated, with GND as the shared spine between:

```
 top edge   ───────────────────  +5V rail   (red)        ← feeds every 595 VCC + MR
            [ 595 #1 ][ 595 #2 ] ... [ 595 #11 ]          ← shift-register row
            ───────────────────  SH_CP rail (green)       ← clock, every 595 pin 11
            ───────────────────  ST_CP rail (white)       ← latch, every 595 pin 12
            ───────────────────  GND  rail  (black)  ★    ← the spine: every chip GND, PSU GND, Mega GND
            [ULN #1 ][ULN #2 ] ... [ ULN #11 ]            ← driver row
            ═══════════════════  +12V rail  (orange) ▓    ← heavy: every ULN COM + every solenoid high side
 bottom     [========= 88-pin OUTPUT HEADER =========]    ← ULN outputs → solenoids
```

- **+5 V rail** (red, top): feeds each 595's VCC (pin 16) and MR (pin 10).
- **SH_CP rail** (green) and **ST_CP rail** (white): the two clock/latch signals are shared by all 11 shift registers, so they're rails too — tap every 595 pin 11 to the green rail, every pin 12 to the white rail.
- **GND rail** (black, the spine ★): every chip's GND, plus the reservoir cap, plus the one tie to PSU GND and Mega GND. Make this generous.
- **+12 V rail** (orange, heavy ▓): every ULN COM (pin 10) and every solenoid's high-side lead. **This one carries real current** — fired solenoids pull 300 mA each, several at once. Use a **doubled 22 AWG run or a thick tinned wire**, and feed it from the PSU with the **18 AWG silicone**. Keep it on the driver side, away from the 5 V rail.

### Star ground (do this, it prevents weird faults)

"Star ground" = all grounds meet at **one** point, not in a daisy chain. In practice: your **GND rail is the spine**, and you tie **PSU GND** and **Arduino Mega GND** to that rail **at one spot each** (ideally near each other). Every chip's GND pin taps the same rail. This keeps the heavy solenoid return current from flowing *through* your logic ground and corrupting the signals. The single most common "it works on the breadboard but the soldered board glitches" cause is a sloppy ground — so build the spine first and tap everything to it.

> **The cardinal rule, physically:** the +5 V rail and the +12 V rail must have **zero** copper between them. The *only* electrical connection between the 5 V world and the 12 V world is the shared **GND rail**. Before powering up you'll meter +5 V↔+12 V and expect infinite resistance (open).

---

## 7. Capacitors — decoupling + reservoir

Two kinds, two completely different jobs and rules.

### A) Decoupling caps — 0.1 µF ceramic (NON-polarized) — one per chip, 22 total

**Job:** when a chip switches, it gulps a spike of current. The 0.1 µF sits right at the chip's power pins and supplies that spike locally, so the rail doesn't dip and ring. Skipping them → random glitches that are *miserable* to debug. They're cheap insurance; never omit.

**Placement — as close to the chip's power pins as physically possible:**

- **74HC595:** across **VCC (pin 16) ↔ GND (pin 8).**
- **ULN2803A:** it has no logic VCC — put its 0.1 µF across **COM (pin 10, +12 V) ↔ GND (pin 9)** to snub the inductive switching noise from the solenoids. (This is the ULN's entry in the "22 total.")

**How to land it (non-polarized, so either way round):**

1. Bend the two legs so they straddle the two target pads (e.g., the pads right at pin 16 and pin 8).
2. Push it down close to the board, legs through the holes.
3. Solder both legs on the bottom, **trim flush.** Keep the legs **short** — long legs add inductance and defeat the cap.

If the two power pins aren't on adjacent holes, put the cap on the two nearest empty holes and run two **short** jumpers to VCC and GND. Short is the whole point.

### B) Reservoir / bulk cap — electrolytic (POLARIZED) — on the 12 V rail

**Job:** a local tank of charge on the 12 V rail so the inrush when a solenoid energizes doesn't sag the whole rail. Single cell: **470 µF** (or larger). Full board: **4700 µF 25 V** across the 12 V input.

**POLARITY — this one bites:**

- Electrolytics have a **+** and a **−** leg. The **stripe/arrow** printed on the can marks the **NEGATIVE (−)** leg. The **longer** leg is **POSITIVE (+)**.
- **+ leg → +12 V rail (orange). − leg (stripe) → GND rail (black).**
- **Reverse it and it overheats and can burst** (loud pop, hot electrolyte). Double-check before soldering and again before first power.
- **Voltage rating:** a 25 V cap on a 12 V rail is correct (rule of thumb: rating ≥ ~1.5–2× the rail). Never use one rated *below* the rail.

**How to land it:**

1. Identify + (long leg) and − (stripe side). Decide which holes are +12 V and which are GND **before** inserting.
2. Insert legs (it stands vertical), bend them slightly on the bottom so it won't fall out.
3. Solder both — these legs carry more current, so give a solid joint — then trim.
4. Place it **near the ULN COM / output side** on the full board (where the inrush happens), close to the 12 V input.

---

## 8. Stage 1 — practice (scrap only, ~1–2 h)

Before any real part, get the motion. On scrap perfboard + spare header pins:

1. Solder **20–30 header pins.** Cut them off, do it again. Goal: a clean pin in **under 90 s** without thinking.
2. Solder **10 wires to header pins** (tin the wire end first). This is exactly the jumper move from §4.
3. **Lay a 10-hole bus wire** (§6) and solder every hole — this is the rail skill, rehearsed on scrap.
4. **Make 2 bridges on purpose and clear them with wick.** You'll make real ones; own the fix.
5. **Desolder a pin** with wick/sucker and re-seat it.

**Move on when:** consistent shiny cones, you can run a straight tacked-down bus, and you can clear a bridge on demand.

---

## 9. Stage 2 — wire ONE cell + fire the 2×2 (Week-2 milestone)

This is the whole board in miniature. Get it perfect; Stage 3 is this ×11.

### 9a. Breadboard first (no soldering)

Prove the circuit before committing it (straight from `firmware/README.md`):

- **`sr_led_walk.ino`** — 1× 595 + 8 LEDs (330 Ω each, Q0–Q7→LED→GND). A bit should walk across the LEDs → proves DS/SH_CP/ST_CP.
- **`keyboard_v0.ino`** — swap LEDs for 1× ULN2803A → your 4 prototype solenoids on 12 V. `FIRE 0`…`FIRE 3` → four crisp clicks.

### 9b. Solder the cell — exact build order

Place the cell at the **left** of the board; leave room to the right (this is cell #1 of 11). Coordinates are yours from the §3 sketch; pin numbers below are the connections.

**Step 1 — Sockets.** Drop in the **DIP-16** socket (for the 595) and the **DIP-18** socket (for the ULN), a few rows apart. Note the **notch = pin-1 end**; orient both the same way. Tack **2 diagonal corners** of each, check they sit dead flat, then solder all pins. **The ICs themselves go in last — never solder a chip.**

**Step 2 — Rails first** (before the board gets crowded). Lay these as bare bus wires (§6):
- **+5 V** rail (red feed) along the top.
- **GND** rail (black) — the spine.
- **+12 V** rail (orange, heavier) on the ULN side.
Keep +5 V and +12 V apart.

**Step 3 — 595 power + decoupling:**
- pin 16 (VCC) → +5 V rail
- pin 8 (GND) → GND rail
- pin 13 (OE̅) → GND rail (outputs always enabled)
- pin 10 (MR̅) → +5 V rail (don't reset)
- **0.1 µF** across pin 16 ↔ pin 8, legs short.

**Step 4 — ULN power + decoupling:**
- pin 9 (GND) → GND rail
- pin 10 (COM) → +12 V rail (**enables the flyback diodes — never skip**)
- **0.1 µF** across pin 10 ↔ pin 9.

**Step 5 — Logic, 595 → ULN, one-to-one** (eight insulated jumpers). Q0–Q7 map to IN1–IN8:

| 595 output (pin) | → | ULN input (pin) |
|---|---|---|
| Q0 (15) | → | IN1 (1) |
| Q1 (1) | → | IN2 (2) |
| Q2 (2) | → | IN3 (3) |
| Q3 (3) | → | IN4 (4) |
| Q4 (4) | → | IN5 (5) |
| Q5 (5) | → | IN6 (6) |
| Q6 (6) | → | IN7 (7) |
| Q7 (7) | → | IN8 (8) |

**Step 6 — Control lines to the Mega** (flying leads to a 3-pin header, or Dupont):
- pin 14 (DS) → Mega **D11** — *blue*
- pin 11 (SH_CP) → Mega **D12** — *green*
- pin 12 (ST_CP) → Mega **D13** — *white*
- one **GND** wire: Mega GND → GND rail (this is the logic-side half of the star ground).

**Step 7 — Outputs:** ULN OUT1–OUT8 (pins 18→11) → an **8-pin output header**. Then each solenoid: **one lead → a header pin, other lead → +12 V rail.**

**Step 8 — Reservoir cap:** **470 µF** across +12 V ↔ GND, **+ leg to +12 V, stripe to GND** (§7B). Near the ULN.

**Step 9 — Star-ground tie:** PSU GND → GND rail, at one point (Mega GND already tied in Step 6).

→ Then **§11** (test cold, power 5 V only, then add 12 V) and `FIRE 0 40`…`FIRE 3 40`. Tune with `PULSE` (firmware found **~22 ms** good on the 2×2; 30–40 ms safe start).

> **Milestone:** first fire from a *soldered* board. Film the click; commit the working-cell photo + firmware tweak to GitHub.

---

## 10. Stage 3 — the full 88-channel board (Week 5, ~260 joints)

You've built 1 of 11 cells. Now repeat it, sharing the rails. **Work in horizontal passes across all 11**, not one whole cell at a time — it's faster and more uniform.

**Plan on paper first:** 11 DIP-16 + 11 DIP-18 sockets in two rows; rails per the §6 floor plan; an **88-pin output header** along the bottom (84 → solenoids, 4 spare). Measure your Stage-2 cell width × 11 — if it won't fit one board, bridge two before you start.

**Build order (pass by pass):**

1. **All 22 sockets.** Diagonal-tack, check flat, finish. Same pin-1 orientation across the row.
2. **All five rails, full width:** +5 V, GND spine, +12 V (heavy), SH_CP, ST_CP (§6).
3. **All 22 decoupling caps** (§7A) — 595s across 16↔8, ULNs across 10↔9.
4. **Per-cell power taps ×11:** each 595 pin16→+5 V, pin8→GND, pin13→GND, pin10→+5 V; each ULN pin9→GND, pin10→+12 V.
5. **Per-cell logic ×11:** the eight Q0–Q7 → IN1–IN8 jumpers (the §9 Step-5 table), repeated for every cell.
6. **The SR cascade chain:** jumper **Q7′ (pin 9) of chip N → DS (pin 14) of chip N+1**, for N = 1…10. Chip **#1's DS (pin 14) → Mega D11** (blue). This is the only DS that goes to the Mega; the rest chain.
7. **Common clock + latch:** tap **every** 595 pin 11 → SH_CP rail (green, → Mega D12); **every** pin 12 → ST_CP rail (white, → Mega D13).
8. **Output header (88 pins):** ULN outputs → header; +12 V distributed to every solenoid high side.
9. **4700 µF reservoir** across the 12 V input (+ to +12 V, stripe to GND).
10. **Star ground:** PSU GND + Mega GND → the GND spine, one point.

**Test each cell as you finish its column** — continuity-check it then and there. Finding one bad joint in 60 is easy; in 260 it's misery.

→ Then **§11**, then flash **walk mode** (cycle channels 0–83, ~100 ms each) and run **one** test solenoid down the 88-pin header: every channel should click; 84–87 do nothing (or a status LED).

**Acceptance:** all 84 channels click in sequence on the roving test solenoid → cleared for Week 6 (mount + wire all 84). Time-lapse it for the "260 joints" reel.

---

## 11. First power-up + continuity testing

**Always test cold (unpowered) with the multimeter on continuity (the beep) before applying any power.**

Check, in order:
1. **Shorts that must NOT exist** (expect silence / open):
   - +5 V rail ↔ +12 V rail
   - +5 V rail ↔ GND rail
   - +12 V rail ↔ GND rail
   - any output/header pin ↔ its neighbor
2. **Connections that MUST exist** (expect beep):
   - every 595 pin 16 ↔ +5 V rail; every pin 8 ↔ GND rail
   - every ULN pin 10 ↔ +12 V rail; every pin 9 ↔ GND rail
   - the cascade unbroken: chip N pin 9 ↔ chip N+1 pin 14, all the way down
   - SH_CP rail ↔ every 595 pin 11; ST_CP rail ↔ every 595 pin 12
   - GND rail ↔ PSU GND ↔ Mega GND (one common net)
3. **Reservoir cap polarity:** + leg on +12 V, stripe on GND. Look twice.

**Power-up sequence:**
1. **5 V logic only** — no 12 V, no solenoids. Seat the ICs (pin-1 right). Power the Mega/5 V rail. Feel each chip: **anything hot or any smell → cut power immediately** and recheck. Run the LED-walk / a no-solenoid FIRE; outputs should toggle.
2. **Add 12 V last** — PSU off, connect the 12 V feed, then power on. Connect a test solenoid and `FIRE`. Crisp click, full retract, no buzz.

Keep one hand near the kill switch on every first power. The PSU is conservatively rated but mechanical things surprise you.

---

## 12. The 5 gotchas that kill driver boards

Tape this above the bench.

1. **ULN COM (pin 10) → +12 V on every chip.** No flyback = a dead driver on the first solenoid.
2. **5 V and 12 V never touch.** Only the grounds tie, at one star point.
3. **Socket every IC.** Never solder the chip itself.
4. **0.1 µF across every chip's power pins** — all 22, legs short.
5. **Reservoir cap polarity** (+ to 12 V, stripe to GND) and **test cold → 5 V-only → 12 V last.**

---

## 13. Pin reference

### 74HC595 shift register — DIP-16

| Pin | Name | Connect to |
|----:|---|---|
| 1 | Q1 | ULN IN2 (pin 2) |
| 2 | Q2 | ULN IN3 (pin 3) |
| 3 | Q3 | ULN IN4 (pin 4) |
| 4 | Q4 | ULN IN5 (pin 5) |
| 5 | Q5 | ULN IN6 (pin 6) |
| 6 | Q6 | ULN IN7 (pin 7) |
| 7 | Q7 | ULN IN8 (pin 8) |
| 8 | GND | GND rail |
| 9 | Q7′ | **DS (pin 14) of the NEXT 595** (cascade) |
| 10 | MR̅ | +5 V rail (don't reset) |
| 11 | SH_CP | SH_CP rail → Mega **D12** (green) |
| 12 | ST_CP | ST_CP rail → Mega **D13** (white) |
| 13 | OE̅ | GND rail (outputs always on) |
| 14 | DS | from **prev 595 Q7′** (or Mega **D11** blue, for chip #1) |
| 15 | Q0 | ULN IN1 (pin 1) |
| 16 | VCC | +5 V rail (+ 0.1 µF to GND) |

### ULN2803A Darlington array — DIP-18

*Outputs run in reverse: IN1→OUT1 is pin 1→pin 18; IN8→OUT8 is pin 8→pin 11.*

| Pin | Name | Connect to |
|----:|---|---|
| 1 | IN1 | 595 Q0 (pin 15) |
| 2 | IN2 | 595 Q1 (pin 1) |
| 3 | IN3 | 595 Q2 (pin 2) |
| 4 | IN4 | 595 Q3 (pin 3) |
| 5 | IN5 | 595 Q4 (pin 4) |
| 6 | IN6 | 595 Q5 (pin 5) |
| 7 | IN7 | 595 Q6 (pin 6) |
| 8 | IN8 | 595 Q7 (pin 7) |
| 9 | GND | GND rail (common) |
| 10 | COM | **+12 V rail** (enables internal flyback diodes) |
| 11 | OUT8 | solenoid 8 low side |
| 12 | OUT7 | solenoid 7 low side |
| 13 | OUT6 | solenoid 6 low side |
| 14 | OUT5 | solenoid 5 low side |
| 15 | OUT4 | solenoid 4 low side |
| 16 | OUT3 | solenoid 3 low side |
| 17 | OUT2 | solenoid 2 low side |
| 18 | OUT1 | solenoid 1 low side |

*Each solenoid's other lead → +12 V rail. The ULN sinks the low side to GND when its input goes high.*

### Arduino Mega → board

| Mega pin | Net | Color | Goes to |
|---|---|---|---|
| D11 | DS | blue | 595 **#1** pin 14 only |
| D12 | SH_CP | green | SH_CP rail (all 11) |
| D13 | ST_CP | white | ST_CP rail (all 11) |
| GND | GND | black | GND rail (star point) |

---

## 14. Pacing + GitHub

| Session | Time | Do |
|---|---|---|
| 1 | ~1–2 h | Stage 1 practice — clean pin <90 s, run a bus, clear a bridge. |
| 2 | ~2–3 h | Stage 2 — breadboard, then wire one cell, then fire the 2×2. |
| 3 | ~6–10 h (splittable) | Stage 3 — full board in passes + walk-mode on all 84. |

**Commit this guide now.** Then commit a photo + the passing-test note at each milestone — first clean joint, first soldered-cell fire, walk-mode pass. Those are exactly the weekly-retro milestones your repo is built around.

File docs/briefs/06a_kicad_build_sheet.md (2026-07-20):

# Brief 06a — KiCad build sheet (6-cell driver board)

**Companion to brief 06 (the electrical spec — that stays the source of truth). This file = the KiCad-specific recipe: exact symbols, footprints, reference designators, and net names.** Written July 16, 2026 during the design session (tool switched EasyEDA → KiCad so Claude can verify the text-format project files directly in the repo).

Project location: `pcb/solenoid_driver/` in this repo. KiCad 9.x, stock libraries only.

## Reference designator scheme (self-documenting)

Cell *n* (1–6): 595 = **U{n}1**, ULN = **U{n}2**, 595 decoupling cap = **C{n}1**, output terminals = **J{n}1–J{n}4** (4× 2-pos = 8 positions, OUT1..8 left to right).
Board-level: **J70** = 12V input terminal · **J71** = cascade IN header · **J72** = cascade OUT header · **R1** = 10k OE pullup · **CB1** = 4700µF bulk (12V) · **CB2** = 100nF (12V) · **CB3** = 100nF (5V).

## Symbols + footprints (place these)

| Qty | Part | Symbol (library:name) | Footprint |
|---|---|---|---|
| 6 | 74HC595 | `74xx:74HC595` | `Package_DIP:DIP-16_W7.62mm` (DIP socket fits this) |
| 6 | ULN2803A | `Transistor_Array:ULN2803A` | `Package_DIP:DIP-18_W7.62mm` |
| 25 | 2-pos screw terminal (24 out + 1 power) | `Connector:Screw_Terminal_01x02` | `TerminalBlock:TerminalBlock_bornier-2_P5.08mm` |
| 2 | 6-pin cascade header | `Connector_Generic:Conn_01x06` | `Connector_PinHeader_2.54mm:PinHeader_1x06_P2.54mm_Vertical` |
| 1 | 10k resistor | `Device:R` | `Resistor_THT:R_Axial_DIN0207_L6.3mm_D2.5mm_P10.16mm_Horizontal` |
| 8 | 100nF ceramic (104) | `Device:C` | `Capacitor_THT:C_Disc_D8.0mm_W5.0mm_P5.00mm` (5.00 vs 5.08 pitch — fine for radial leads) |
| 1 | 4700µF 25V electrolytic | `Device:C_Polarized` | `Capacitor_THT:CP_Radial_D18.0mm_P7.50mm` — **MEASURED Jul 16: can Ø17mm × 25mm tall, lead pitch ~8mm (→ standard 7.5). Can height 25mm feeds the brief 07 deck clearance stack.** |
| 4 | M3 mounting hole | `Mechanical:MountingHole_Pad` | `MountingHole:MountingHole_3.2mm_M3` |

## Net names (use net labels, not long wires)

Global power: `+5V`, `+12V`, `GND` (use the power symbols).
Buses: `DATA_IN` · `SCLK` (=CLK, Mega D12) · `RCLK` (=LATCH, Mega D13) · `~OE` · cascade hops `CASC1`…`CASC5` · `DATA_OUT`.
Per cell, Q→IN connections can be drawn as direct short wires (place U{n}1 immediately left of U{n}2) — no labels needed.

## Pin-by-pin — 74HC595 (U{n}1, DIP-16)

| Pin | Name | Connect to |
|---|---|---|
| 16 | VCC | +5V |
| 8 | GND | GND |
| 14 | DS (SER) | cell 1: `DATA_IN` · cell n: `CASC{n-1}` |
| 11 | SHCP (SRCLK) | `SCLK` bus |
| 12 | STCP (RCLK) | `RCLK` bus |
| 10 | ~MR (SRCLR) | +5V |
| 13 | ~OE | `~OE` bus |
| 9 | Q7' (Q7S) | cell 1–5: `CASC{n}` · cell 6: `DATA_OUT` |
| 15 | Q0 | ULN IN1 (pin 1) |
| 1–7 | Q1–Q7 | ULN IN2–IN8 (pins 2–8) — **canonical, in order** |

## Pin-by-pin — ULN2803A (U{n}2, DIP-18)

| Pin | Name | Connect to |
|---|---|---|
| 1–8 | IN1–IN8 | 595 Q0–Q7 (above) |
| 18–11 | OUT1–OUT8 | terminals: J{n}1 pin1=OUT1, pin2=OUT2 · J{n}2 = OUT3/4 · J{n}3 = OUT5/6 · J{n}4 = OUT7/8 |
| 9 | GND | GND |
| 10 | COM | **+12V (flyback — never skip)** |

## Board-level

- **J70 (12V in):** pin 1 → +12V, pin 2 → GND. Attach `PWR_FLAG` to +12V and GND here (ERC needs it).
- **J71 (cascade IN):** 1→+5V · 2→GND · 3→`DATA_IN` · 4→`SCLK` · 5→`RCLK` · 6→`~OE`. Attach `PWR_FLAG` to +5V here (5V enters the board through this header from the Mega).
- **J72 (cascade OUT):** 1→+5V · 2→GND · 3→`DATA_OUT` · 4→`SCLK` · 5→`RCLK` · 6→`~OE`.
- **R1:** `~OE` → +5V (the 10k pullup — outputs disabled until the Mega drives OE).
- **CB1 (4700µF):** +12V to GND. **Polarity: + to +12V.** Place near J70.
- **CB2 (100nF):** +12V to GND, next to CB1. **CB3 (100nF):** +5V to GND, near J71.
- **C{n}1 (100nF):** +5V to GND, one physically adjacent to each 595.

## Workflow checklist

1. Schematic: build **cell 1 completely** → Claude verifies the `.kicad_sch` → copy-paste ×5 → fix per-cell labels (DS/Q7' chain) → board-level parts.
2. **Annotate** (Tools → Annotate Schematic) — keep the U{n}1/U{n}2 scheme (set refs manually as you place; paste-copies annotate with fresh numbers, rename to scheme).
3. **ERC** → expect PWR_FLAG complaints if step "Board-level" missed → fix to zero errors.
4. Assign footprints (table above) → **Update PCB from Schematic** (F8).
5. Layout: Edge.Cuts ≤100×100mm · terminals along 3 edges · chips in 6 rows/columns matching cells · route: OUT traces ≥0.6mm, GND+12V ≥2mm or zone pours (GND pour bottom, +12V pour top around terminals) · silkscreen `S{n}-OUT{m}` + blank Sharpie box per terminal.
6. **DRC** to zero errors. JLCPCB limits (2-layer): ≥0.127mm trace/space — we're nowhere near.
7. 1:1 paper print (File → Print, scale 1.0) — set real parts on it, check terminal spacing.
8. Plot Gerbers (F.Cu, B.Cu, F.SilkS, B.SilkS, F.Mask, B.Mask, Edge.Cuts) + drill files → zip → upload to jlcpcb.com/quote → 2-layer, 1oz, HASL, **qty 5** → cheapest ~1wk shipping.
9. Export board outline + the 4 mounting-hole coordinates → brief 07 Track B (deck CAD datum).
10. **git add pcb/ + commit + push — milestone.**

## Populate plan (unchanged from brief 06)

Board A = cells 1–6 (ch 0–47). Board B = same PCB, populate slots 1–5 only (ch 48–87), slot 6 socket EMPTY — board B goes LAST in the cascade. 3 spare bare boards.

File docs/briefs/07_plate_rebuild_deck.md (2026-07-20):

# Brief 07 — Full plate rebuild + top deck (master plan)

> **AMENDED July 15 (later): the fastening scheme changed.** Daniel chose his own scheme over brief 03's drop-in pockets: **groove-sandwich removable walls** (tab screws kept; walls are separate parts keyed into plate grooves below and deck grooves above; deck held down by end posts + wall-top screws). Full spec + Fusion steps in **`08_groove_sandwich_cad.md`** — read it wherever this brief says "brief 03 scheme" or "clamp bars". Tracks/gates below are unchanged; the coupon is now brief 08's groove coupon. Caliper gate `d` (ledges) is no longer needed; body-top height + lead exits still are. Clamp-bar buy list (EVA foam) is replaced by brief 08's (inserts + M3×8 still needed, more of them).

**Decision (July 13, 2026, with Daniel; planned July 15):** rebuild the 84-key plate NOW using brief 03's drop-in pocket + clamp-bar scheme (revived), with two new requirements: **wires route straight UP** and a **top deck carries both driver PCBs**. Drivers: wiring dread, repair fear, no PCB home, elegance. The rebuild lands during the ~2wk PCB lead so no calendar time is lost.

**Confirmed choices (July 15):**
- **Teardown gate: the old plate stays fully assembled until the coupon passes** (swap cycle + fire). Zero risk of being stranded plateless if the pocket scheme fails on real plastic.
- **PCB order is NOT blocked by anything CAD.** Order first; the deck is designed around the ordered board's exact outline + mounting-hole coords, not vice versa. (Brief 06's terminal-edge placement is already fixed by that design.)

## What the deck changes about the harness (supersedes part of §Harness in CLAUDE.md)

The boards now live ON the plate assembly, directly above the solenoids. Consequences:

- **The 85-wire plate↔board harness is gone.** There is no "off to the board across the desk" run anymore.
- Per solenoid: **both leads route straight up** — high side to a **+12V bus on/under the deck** (bus wire relocates from wall-tops to the deck; same bare 16 AWG + one 18 AWG feed from the board's 12V terminal), low side up through a **deck pass-through slot** to its screw terminal on the PCB above.
- Wires get dramatically shorter (~40–80mm vs 300+mm), which is most of the wiring-dread win.
- **Unchanged rules:** MAP discipline (Sharpie the terminal's silkscreen box, log `cell · OUT · key` at landing), golden rule (cut to length only at the moment of landing), solid-vs-stranded (stranded into screw terminals, no tinning — ferrules optional).
- Wire-tidy Phases 1–2 (velcro bundles, wall-top buses) are **obsolete**. Phase 0 (snip/tape every frayed tip) is still mandatory before any handling.

## Deck design requirements (new part — CAD during the PCB lead)

1. **Carries both PCBs**: M3 mounts matching the ordered board's mounting-hole coords (export from EasyEDA after DRC; don't guess). Standoffs or printed bosses; boards face terminals-outward/up for screwdriver access.
2. **Wire pass-through slots** aligned with the rows below, sized for 14–16 leads per row plus slack; edges chamfered (no insulation chafe on PLA edges under vibration).
3. **+12V bus routing** on/under the deck: bus wire channels or printed clips; one 18 AWG feed drops to the board's 12V input terminal. No pinch points under the boards.
4. **Clearance stack (bottom-up):** plate → solenoid body tops (≈Z34 if d=7 — caliper gate) → clamp bars + screw heads → lead service loop → deck underside. Leave enough gap to get fingers/driver onto the clamp-bar screws WITHOUT removing the deck, if feasible; otherwise the deck must remove with ≤4 screws.
5. **Airflow**: the 80mm USB fan needs a path; deck must not seal the solenoid bay (thermal risk is documented). Cutouts between wire slots.
6. **Supports**: deck lands on the raised walls (brief 03 raises them to body-top+2mm) or on corner posts off the side rails — decide in CAD after caliper gate #2. Deck must be removable without disturbing landed wires (slots open to an edge, or generous service loops).
7. **Cascade + Mega**: 6-pin dupont cable Board A→B lives on the deck; Board A's IN header needs reach for the Mega jumpers — leave a cable exit toward wherever the Mega sits.
8. Footprint ~320×130 like the plate → **split deck L/R** with the same seam-bridging trick if the bed can't fit it.

## Sequence (gates in bold; nothing starts before its gate)

**Track A — electronics (critical path, start immediately):**
1. EasyEDA design session (Claude drives via Chrome; Daniel needs a JLCPCB account) → netlist beep-check against brief 06 → DRC → 1:1 paper print of layout → **order 5 boards ASAP** (per Jul 13: not gated on cell #1 — the breadboard fire test was the design gate).
2. Same day: export board outline DXF/dims + mounting-hole + terminal coords → feed Track B step 4.
3. Buy list on order day: screw terminals, DIP sockets (reuse perfboard ones if on hand), heat-set inserts + M3×8 pan heads + EVA foam (brief 03 clamp hardware — now needed again).

**Track B — mechanical (runs inside the ~2wk lead):**
1. Wire-tidy Phase 0 only: snip/tape all frayed tips on the populated plate. 10 min, do before any bench work near 12V.
2. **Caliper gates (brief 03, on the 2×2, 10 min):** d = body-bottom→lower-tab-hole; body-top height above plate; lead exit points. These size the ledges, wall raise, and bar slots.
3. Coupon print: 3-wall × 2-column interior section per brief 03 — sandwich fit, ribs, seat ledges, insert boss, bar preload, **one full vertical swap cycle + a fire** (breadboard driver — cell #1 chips; cell #1 board is parked). **GATE: coupon passes → old-plate teardown is authorized.** Coupon fails → fallback is the T-stud keyhole scheme (brief 03 §Rejected); old plate untouched either way.
4. Full CAD: plate L/R (locked params + `Full_84Key_Hole_Coordinates.csv`), walls with pockets/ribs/ledges/bosses, clamp bars **with vertical lead-exit slots (leads go UP through/past the bar, not sideways)**, deck L/R per requirements above. Write the full assembly sequence BEFORE finalizing geometry — anything not reachable vertically is a geometry bug.
5. Print everything. Plate + walls first (longest), bars + deck after.

**Track C — merge (boards arrive, ~Jul 29–Aug 5):**
1. Board A/B: sockets/terminals/caps → cold continuity gate → chips in → WALK 0–87 per brief 06 DoD (roving clipped spare).
2. **One rebuild session:** teardown old plate (168 screws out, one-time) → drop-in populate new plate row by row → foam + bars → mount deck + boards → land all 84 grey wires up through the slots (label + log) → +12V bus + feed → Mega hookup.
3. Flash keyboard_v1 → MAP from the solder-time log → WALK all 88 → first full-plate typing. **git push — this is the milestone of milestones.**

**Parallel, hardware-free (any wait time):** vision calibration (milestone 3 non-driver parts), `agent/tft/set_data.json`, firmware header comment fix (2-board split) once boards verified.

## Spreadsheet impact (NOTE ONLY — ask-first before editing)

All pending TODOs in CLAUDE.md still stand. Delta from this brief: brief 03's clamp hardware (M3 heat-set inserts ~30, M3×8 pan heads ~30, 3mm EVA foam tape) moves from "no longer needed" back to **BUY**. Row 39 M3×3 flat-heads: now legacy (2×2 only) after the rebuild.

## Definition of done

Coupon passed (swap + fire) · new plate populated + deck mounted with both boards · WALK 0–87 green · all 84 wires landed + logged · dimension doc written (like `2x2_Prototype_Dimensions.md`) · CLAUDE.md session record · commit + **git push**.

## UNVERIFIED

- Pocket/clamp scheme is paper until the coupon (inherited from brief 03).
- Deck clearance stack has zero measured numbers yet — everything hangs on caliper gates 1–3.
- 4700µF can diameter/lead pitch still to be measured in mm before PCB layout (brief 06).

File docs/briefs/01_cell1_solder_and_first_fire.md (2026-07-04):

# Brief 01 — Cell #1: solder, continuity gate, first fire

**Goal:** turn the dry-fit cell #1 (Mega → 74HC595 → ULN2803A → solenoid) into a soldered, verified, firing unit. This is a filmable milestone.

## Context you must hold

- Source docs: `Soldering_Plan.md`, `OneCell_595_ULN_Build_and_Fire_Guide.md`, `TopSide_Wiring_CutList.md`, `Cell_TopSide_Routing.svg`.
- As-built decisions (CANONICAL, do not re-litigate): ULN flipped (notch RIGHT), Q→IN canonical order (Q0→IN1 … Q7→IN8), jumper fan lengths 70/65/60/55/50/50/55/60mm (Q0…Q7), solder longest-first (IN1→IN8), consistent crossing layering. OUT landing holes run right-to-left (OUT1 far right) — chip-internal, independent of jumper scheme.
- 2-2-2-2 middle-rail spacing, 11-row chip gap.
- ULN COM (pin 10) → +12V rail. **Never skip — it's the flyback diodes.**
- Solid wire on board; solid→stranded transition at the landing hole only.

## Order of operations

1. Rails first (per `Soldering_Plan.md`), then sockets, then jumper fan longest-first.
2. **Cold continuity gate BEFORE chips are inserted and BEFORE any power:** beep every rail (5V, GND, 12V — verify NO 5V↔12V or rail↔rail shorts), every Q→IN path, every OUT→landing hole, COM→12V. Chips out of sockets during all of this.
3. Insert chips (595 + ULN, correct orientation — ULN is FLIPPED relative to naive placement; double-check notch direction against `Cell_TopSide_Routing.svg`).
4. **Power-on order: Arduino/USB FIRST, then 12V.** 595s output random data until cleared — 12V-first can fire random solenoids.
5. One solenoid on OUT1 → `FIRE 0` from keyboard_v1 (or keyboard_v0 single-cell test). Expect: FIRE N → OUT(N+1).
6. Walk all 8 channels with one roving solenoid before landing real wires.

## Failure modes to check first

- No fire at all → COM pin, power-on order, cascade wiring (D11/D12/D13), 12V rail actually energized.
- Wrong channel fires → jumper fan crossing error; re-beep Q→IN paths.
- Solenoid stays energized → stuck 595 output (power-on order) or solder bridge on OUT.
- Chip gets hot fast → reversed ULN or 5V/12V short. Kill power immediately.

## Definition of done

All 8 channels fire the roving solenoid correctly; nothing warm at idle; milestone filmed; commit + **git push**; CLAUDE.md session record appended.

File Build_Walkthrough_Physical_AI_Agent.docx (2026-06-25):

Physical AI Agent

Build Walkthrough

Companion to PRD v2.0

Owner: Daniel Baek

For: Summer 2026 build

# 0. How to Use This Document

This walkthrough is the operational companion to the PRD. The PRD says what we are building and why. This document says, week by week, exactly what to buy, what to build, and what to test. It is written for one specific reader (Daniel) with a known starting point: comfortable with basic Python and basic Arduino, beginner CAD, owns an FDM 3D printer and a 14-inch MacBook Pro, will buy a soldering kit, has roughly 20–30 hours per week for a 12-week build over summer break.

Each week has three sections: Goals, Build steps, and Acceptance test. Do not move to the next week until the current week's acceptance test passes. Slipping a week is fine; lying to yourself about whether the test passed is not.

Rule of the build: every subsystem gets a "lights-on" test before integration. A solenoid that works alone is not a solenoid that works in a matrix. Always verify alone, then verify together.

# 1. Pre-Flight: Tools and Skills

## 1.1 Tools you must own

- Soldering iron (temperature-controlled, 60 W class). A Pinecil V2 or Hakko FX-888D is ideal. A no-name 30 W pencil iron will work but you will hate it by week 5.
- Solder: 0.6 mm or 0.8 mm diameter, leaded if locally legal (much easier for beginners), with rosin core. Avoid lead-free unless required.
- Flux pen and solder wick (for fixing mistakes).
- Wire cutters, wire strippers (auto-adjust strippers strongly recommended).
- Digital multimeter (any $20+ model with continuity, DC voltage, and resistance).
- Heat-shrink tubing assortment, lighter or heat gun.
- Hex key set (the 2020 V-slot ecosystem is all M3/M4/M5 hex).
- Phillips and flat screwdrivers (for the PSU terminal block).
- Safety glasses (mandatory while soldering).
- A heat-resistant work mat and a small fan or open window for solder fume extraction.
- Calipers (digital, 150 mm). Required for the CAD work.

## 1.2 Skills to practice before week 1

Spend 4–6 hours in the week before the build officially starts on the following. You will save more than that in week 5 alone.

1. Soldering practice. Solder 30 through-hole pin headers onto a scrap perfboard. Then solder 10 wires to header pins. By the end, your joints should look like shiny cones, not blobs. There are many free tutorials on YouTube; "EEVblog soldering tutorial" is a good one.
2. Arduino basics refresher. Flash the Blink sketch. Read a button with digitalRead. Use Serial.print to send a message every second. If any of these are not muscle memory, do them.
3. Fusion 360 (or Onshape) tutorial: the official "Bracket" tutorial covers extrude, hole, and parametric sketches. That is 90 % of the CAD this project needs.
4. Python virtualenv setup. Create a project folder, run python3 -m venv .venv, activate it, pip install opencv-python pyserial numpy. If this is unfamiliar, do it once before week 9.
5. CAD tool note: install Fusion 360 with your free student license, not AutoCAD. AutoCAD is excellent for 2D drafting but is the wrong tool for parametric 3D-printable mechanical design. Fusion 360 is the standard for hobbyist 3D printing and has a deep tutorial library specifically for parts like the ones you will be designing.

## 1.3 Documentation and Content Setup

Since documentation is a first-class project goal, the accounts, repository, and gear all need to exist before week 1 ends. Total time investment: roughly 90 minutes.

6. Create a public GitHub repository named physical-ai-agent (or similar). Initialize with a README and an MIT or CC-BY license. Commit the PRD and this walkthrough on day one. The repository becomes the canonical home for code, CAD, BOM, and weekly retros.
7. Create a dedicated X account for the project. Username should be memorable and on-brand (e.g., your handle plus "/builds" or the project name). Pinned post: link to the GitHub repo and a one-sentence project description.
8. Create a dedicated Instagram account with the same handle pattern. Bio: same one-sentence description, link to GitHub.
9. Install CapCut on your phone (free) and CapCut Desktop on your MacBook (free). iMovie is also acceptable as a fallback.
10. Pick a posting day and stick to it. Recommended: Sunday evening. Every Sunday for 12 weeks, you post that week's update across both platforms.
11. Order the documentation gear with your Wave 1 hardware order: a phone tripod and a clip-on lavalier microphone (see §2.1).

# 2. Master Shopping List

Buy in two waves to avoid being blocked. Wave 1 (week 1) is everything needed for the first 6 weeks (keyboard subsystem and prototyping). Wave 2 (week 6) is everything for the gantry, vision, and integration. Splitting the order also lets you absorb learning before committing to the more expensive items.

## 2.1 Wave 1 — order in week 1

Item | Source | Cost | Notes
JF-0420B 12V micro solenoids ×84 | AliExpress / Amazon bulk listing | $420 | Order 90 to allow for DOA replacements. 4–6 week shipping from AliExpress; 1 week if you pay more on Amazon.
74HC595 shift registers ×12 | DigiKey, Mouser, Amazon multipack | $12 | Get DIP-16 through-hole, not SMD. 11 used, 1 spare.
ULN2803A Darlington arrays ×12 | DigiKey, Mouser, Amazon multipack | $18 | DIP-18 through-hole. 11 used, 1 spare.
Arduino Mega 2560 (genuine or compatible) | Amazon / official store | $25 | Genuine $45, compatible $15–25. Either is fine.
Arduino Uno (genuine or compatible) | Amazon / official store | $20 | Same.
Soldering kit (iron + solder + flux + wick + multimeter) | Amazon "electronics starter kit" | $80 | Pinecil V2 + 60/40 solder + flux pen + cheap multimeter. Spend more if you already know you want it.
Nuphy Air75 V3 with Blush Nano switches | Nuphy direct (nuphy.com) or Amazon | $130 | 84-key 75% low-profile mechanical keyboard. Hot-swappable. Make sure to select Blush Nano linear switches at checkout.
Spare Blush Nano switches ×8 | Nuphy direct | $15 | Replacements for any switches damaged during build. Hot-swap socket means no soldering to replace.
12V 40A switching power supply | Amazon "S-480-12" or equivalent | $60 | Standard CCTV-style aluminum-case PSU. Make sure it is 480W, not 360W.
LM2596 buck converter modules ×2 | Amazon multipack | $8 | Bare boards with input/output pads.
Perfboard ×3 (large, ~10×15 cm) | Amazon multipack | $15 | Single-sided through-hole.
Solid-core hookup wire (assorted colors, 22 AWG) | Amazon multipack | $15 | Need at least 5 colors. 30 ft of each minimum.
Stranded silicone wire 18 AWG (for 12V power runs) | Amazon | $15 | Red and black, 10 ft each.
IC sockets DIP-16 ×10 and DIP-18 ×10 | Amazon multipack | $10 | Always socket the ICs. Saves you on rework.
Pin headers (male, 0.1" pitch) | Amazon strip multipack | $10 | Snap to length as needed.
Dupont jumper wires (M-M, M-F, F-F) | Amazon kit | $10 | Get all three genders.
Capacitors: 4700µF 25V ×2, 0.1µF ceramic ×50 | Amazon multipack | $15 | 0.1µF will be used on every IC.
Heat-shrink tubing assortment | Amazon kit | $10 | 2mm and 5mm sizes used most.
Food-grade silicone tubing 5mm ID | Amazon roll | $10 | For solenoid plunger tips.
PLA filament 1kg (any color) | Amazon / Bambu / Polymaker | $20 | For the matrix plate and other printed parts.
M2 screws + nuts assortment kit | Amazon assortment | $15 | For solenoid retention.
M5 standoff and adjustable standoff hardware | Amazon | $15 | For matrix-to-keyboard height.
Phone tripod (flexible or floor) | Amazon — Joby GorillaPod or generic | $25 | For weekly filming. Tabletop or floor model both fine.
Clip-on lavalier microphone (smartphone) | Amazon — BOYA BY-M1 or similar | $30 | Plug-and-play with phone via Lightning/USB-C adapter. Massive voiceover quality jump over phone built-in mic.
Wave 1 subtotal | | $983

## 2.2 Wave 2 — order around week 6

Item | Source | Cost | Notes
2020 V-slot aluminum extrusion (4 m total) | Amazon / OpenBuilds | $50 | Pre-cut lengths if available, otherwise hacksaw to length.
Corner brackets and T-nuts for 2020 | Amazon kit | $25 | Get a 100-piece assortment.
NEMA 17 stepper motors ×2 | Amazon | $25 | 1.5–1.7A rated. Standard "3D printer" steppers.
CNC Shield V3 + 2× A4988 drivers + heatsinks | Amazon kit | $25 | Comes as a kit; ignore the A axis driver.
GT2 belt 6mm (3m) + 2× 20T pulleys | Amazon | $15 | Pulleys must match the stepper shaft (5mm).
V-slot wheels (8) + bearings + spacers | Amazon / OpenBuilds kit | $25 | Delrin or POM wheels.
Microswitch limit switches ×4 | Amazon multipack | $8 | Two used, two spares.
SG90 micro servo ×2 | Amazon multipack | $5 | Cheapest hobby servo. Plenty for click force.
Logitech B100 USB optical mouse (or any cheap wired) | Amazon | $10 | Sacrifice mouse.
Mousepad, hard surface, large (90×40 cm) | Amazon | $15 | For consistent optical tracking.
Logitech C920 webcam (or comparable 1080p) | Amazon used / new | $70 | Refurbished C920s are $40–50.
Articulating arm webcam mount | Amazon | $20 | Microphone-boom style clamps to the workbench.
Circular polarizing filter (clip-on for webcam) | Amazon photo accessories | $10 | Optional but reduces screen glare significantly.
600×450 mm plywood or HDPE base board | Local hardware store | $20 | Cut to size; ~12mm thickness.
Cable raceway / wire chase 1m | Amazon / hardware store | $10 | Keeps the rear of the rig tidy.
E-stop pushbutton (mushroom head, NC contact) | Amazon industrial | $15 | Wire into the PSU remote-disable or a separate 12V relay.
DC relay (40A, 5V coil) | Amazon | $10 | For E-stop interrupt of 12V to actuators.
XT60 or screw-terminal connectors for 12V distribution | Amazon | $10 | Whichever you prefer.
Misc: zip ties, label maker tape, electrical tape | | $15
Wave 2 subtotal | | $383

## 2.3 Total

Wave 1 + Wave 2 = approximately $1,366. The PRD estimate was $1,325 because the walkthrough breaks the soldering kit out as a tool rather than rolling it into the keyboard subsystem. Either way, plan for $1,350–1,450 to comfortably finish the build, including documentation gear, without scrambling for missing parts mid-summer. Well within the $1,500 ceiling.

# 3. Week-by-Week Build Plan

## Week 1 — Procurement, Tools, Skills

### Goals

- All Wave 1 parts on order.
- Soldering and CAD baseline skills established.
- Project folder created on the MacBook Pro.

### Steps

12. Place the Wave 1 order in one or two carts (Amazon for fast items, AliExpress for bulk solenoids).
13. Practice soldering on scrap perfboard. Solder 30 pin-header pins; cut them off; solder them again. Repeat until joints look clean and uniform.
14. Complete the Fusion 360 "Bracket" tutorial. Save the file. You will not use this file but you will use everything you learned.
15. Create the project folder on the MacBook: ~/Projects/physical-ai-agent/ with subfolders cad/, firmware/, host/, calibration/, docs/.
16. Initialize a git repository in the project folder, even if you do not push it anywhere yet. Commit the PRD and this walkthrough.

### Acceptance test

You can solder a single pin header onto a scrap board in under 90 seconds with a result you are not embarrassed by. You have a CAD file open that you made yourself.

### Document this week

- Film a quick "intro" clip introducing yourself and the project: what you're building, why, the 12-week timeline. 60–90 seconds, vertical.
- Take establishing photos of the desk/bench space and the empty MacBook setup.
- Post: project intro reel on Instagram and X thread linking the GitHub repo, the PRD, and this walkthrough.

## Week 2 — Electronics Prototype

### Goals

- One shift register driving one ULN2803 driving four solenoids works on a breadboard.
- Minimal keyboard firmware reliably fires individual solenoids on serial command.

### Steps

17. Wire one 74HC595 to the Arduino Mega on a breadboard. Use the canonical SR pinout: DS to D11, SH_CP to D12, ST_CP to D13. Run an LED-test sketch that walks lights down the 8 outputs.
18. Insert one ULN2803A between the SR outputs and a solenoid coil. Power solenoids from the 12V PSU; only common ground to the Arduino. The ULN2803A input pins map 1:1 to its output pins.
19. Add three more solenoids on the same ULN2803A.
20. Write firmware/keyboard_v0.ino: it accepts the line "FIRE n m" over serial (where n is a 0–7 channel and m is duration in ms) and energizes that solenoid for that time.
21. Drive the firmware from a terminal (screen or Arduino IDE Serial Monitor). Each FIRE command should click an audible solenoid.

### Acceptance test

You can type "FIRE 0 50", "FIRE 1 50", "FIRE 2 50", "FIRE 3 50" in the serial console and hear all four solenoids click in order. Each click is crisp; none of them buzz or fail to retract.

### Document this week

- Capture clean close-up audio/video of the first solenoid click — this is one of the most satisfying moments of the build.
- Time-lapse the breadboard wiring (set phone on tripod above the bench, take a photo every 2 minutes).
- Post: "first click" reel and X thread explaining shift registers and Darlington arrays in plain English.

## Week 3 — Matrix v0 (4×4)

### Goals

- Parametric Fusion 360 model of a 16-solenoid plate exists.
- Printed 4×4 plate fits over a corner of the external mechanical keyboard.
- Four solenoids actually press four keys reliably.

### Steps

22. Measure the Nuphy Air75 V3 keyboard. Confirm key pitch is 19.05 mm. Note the lower keycap height of the low-profile design — your plate will sit closer to the keys than a standard mech board.
23. In Fusion 360, create a parametric sketch with grid parameters (rows, cols, pitch_x, pitch_y, solenoid_dia=4.2, plate_thickness=4). Extrude to a plate; pattern the solenoid holes on the grid. Use 4 M2 retention holes around each solenoid hole.
24. Print a 4×4 version of the plate. Print at 0.2mm layer height, 30 % infill, 4 walls.
25. Mount 4 solenoids in the plate using M2 screws. Cap each plunger with 5 mm of silicone tubing.
26. Place the plate over four adjacent keys of the Nuphy keyboard, on M5 standoffs adjusted so plungers rest 1–2 mm above keycaps. Low-profile keys mean less travel margin — be precise.
27. Run the FIRE-n test from week 2. Confirm each solenoid actually triggers the key beneath it (the laptop should type the corresponding letters). If the Blush Nano switches register a press but feel mushy, reduce solenoid pulse duration from 50 ms to 30 ms.

### Acceptance test

With the 4×4 plate over keys "ASDF" (or any four adjacent keys), running "FIRE 0..3 30" (note the 30 ms pulse, not 50 ms — calibrated for Blush Nano low-profile switches) produces the four letters in a text editor on the MacBook with no missed presses across 50 trials.

Stop here and fix anything not perfect before scaling up. A misalignment problem on 4 solenoids is an 84x bigger problem at full scale.

### Document this week

- Film the moment of "ASDF" appearing on the screen for the first time as the rig types it. Slow-motion close-up of the solenoids is even better.
- Capture a side-by-side: hand typing the same keys vs. the rig typing them.
- Post: "first robot keystrokes" reel. This is one of the highest-engagement moments of the build — expect strong response.

## Week 4 — Full Matrix CAD

### Goals

- Full 84-key matrix plate designed and printed for the Nuphy Air75 V3 layout.
- Plate dry-fits over the Nuphy keyboard with all 84 solenoids aligned.

### Steps

28. Get the official Nuphy Air75 V3 keycap layout (vendor product page or community keyboard layout files). The Air75 is a 75% layout with a function row, full alpha block, arrow cluster, and a right-hand utility column. It is NOT a uniform grid.
29. Model the layout in Fusion 360 row by row, not as a single rectangular array. Use sketch construction lines per row, with row offsets (stagger) as parameters. Define each row's starting X offset and the number of solenoid positions in that row.
30. Account for the arrow cluster, which sits below the right shift in the bottom row and creates an irregularity. Treat the arrow keys as their own mini-cluster with explicit positions.
31. Account for the right-hand utility column. These keys are slightly offset from the main grid; verify against the actual keyboard with calipers before printing.
32. Add a sandwich plate (top cover) with matching solenoid holes to keep solenoids from drifting upward.
33. Print the plates. The full plate will likely exceed your printer's 220 mm bed; split into 2–3 pieces with dowel-pin or lap joints, designed parametrically as part of the model.
34. Dry-fit over the Nuphy keyboard. Verify visually that every solenoid sits centered over its target keycap. Pay special attention to the arrow cluster and right utility column.

### Acceptance test

Plate fits without forcing. Every solenoid hole is centered on its target key within 1 mm by visual inspection. No solenoid sits at the edge of its hole.

### Document this week

- Time-lapse a long print of the full plate.
- Screen-record a tour of the parametric Fusion 360 model — show how changing pitch parameter updates the whole part.
- Post: "CAD walkthrough" reel. Educational content performs well; people love seeing how parametric design works.

## Week 5 — Driver Board

### Goals

- Full solenoid driver board (11× 74HC595 + 11× ULN2803A) is soldered onto perfboard.
- All 88 channels test live with the walk-mode firmware.

### Steps

35. Plan the perfboard layout on paper first. Roughly: 11 SR + 11 ULN sockets in a 2-row grid, with the SR cascade chain along the top edge. The 84-key version is meaningfully wider than the 71-key version was — you may want a larger perfboard or two boards bridged.
36. Solder all IC sockets first. Never solder ICs directly.
37. Solder the SR cascade chain: Q7' of each SR to DS of the next. Common SH_CP and ST_CP across all 11.
38. Solder the SR-to-ULN connections, channel by channel. SR output pins go to ULN input pins.
39. Solder the screw terminals or pin headers for 12V solenoid outputs. Each ULN output drives one solenoid.
40. Add 0.1µF decoupling caps across VCC/GND of every SR and ULN.
41. Add 4700µF reservoir cap across the 12V solenoid power input.
42. Star-ground: one ground bus running across the board; every component's GND ties to it directly.
43. Continuity-test every connection with a multimeter before powering on.
44. First power-up: only 5V logic side (no 12V solenoids yet). Watch for hot ICs, smell for burning. If anything is wrong, unpower immediately.
45. Update firmware to "walk mode": cycle through all 88 channels, energizing each for 100 ms. Connect a test solenoid to each channel, one at a time, to verify all 88 work.

### Acceptance test

Walk-mode firmware energizes every one of channels 0–83 in sequence, audible click on a test solenoid moved through each channel. Channels 84–87 (the unused 4) intentionally do nothing or drive a status LED.

Week 5 is the highest-risk single week. If you can give it 35 hours instead of 25, do.

### Document this week

- Time-lapse the entire solder session (set phone on tripod above the workbench, record continuously, speed up 30x in CapCut).
- Voice over the time-lapse with what each section of the board does. Educational content about shift register cascades performs surprisingly well.
- Capture the moment when walk-mode test runs successfully through all 88 channels — that satisfying "tick, tick, tick" audio is gold.
- Post: "260 solder joints in 10 hours" reel. Soldering content has a built-in audience.

## Week 6 — Full Keyboard Integration + Wave 2 Order

### Goals

- All 84 solenoids mounted in the full plate.
- All 84 solenoids wired to the driver board.
- Full typing test passes: agent types arbitrary text by serial command.
- Wave 2 order placed.

### Steps

46. Place Wave 2 order on day 1 so it arrives by week 7.
47. Mount all 84 solenoids in the printed plate. This is tedious; budget 5–7 hours.
48. Wire each solenoid to its corresponding driver-board channel. Use 22 AWG stranded wire. Label every pair. This is where the labeled wire pays for itself.
49. Build a key map in the firmware: a static array mapping a character ('a', 'b', ...) plus the Air75 V3 special keys (arrows, function row, right utility column) to a channel number (0–83). Cross-check by visual inspection against the keyboard layout.
50. Implement TYPE "<text>" command in firmware: for each character, energize the mapped channel for 30 ms with 50 ms between presses. The 30 ms duration is tuned for the Blush Nano switches; if you see missed presses, bump to 40 ms.
51. Run a typing test: TYPE "the quick brown fox jumps over the lazy dog". Inspect output on the MacBook in a text editor.
52. Tune: adjust per-key duration if any keys are inconsistent; adjust plate height per row if rows differ.

### Acceptance test

TYPE "the quick brown fox jumps over the lazy dog 1234567890" produces the exact text in TextEdit on the MacBook, with zero errors across 10 consecutive runs.

### Document this week

- THE hero moment of the project so far. Film the rig typing "the quick brown fox jumps over the lazy dog" from multiple angles: top-down, side, screen close-up.
- Capture audio of the solenoid clicks — the rhythm of 30+ keystrokes in a row is mesmerizing.
- Show a side-by-side of the 4-key prototype from week 3 vs the full 71-key rig now.
- Post: "the rig types its first paragraph" reel. This is likely your highest-engagement post of the build.

## Week 7 — Gantry Frame

### Goals

- Cartesian XY gantry frame assembled and squared.
- Steppers wired through CNC Shield, basic motion in raw steps works.
- Homing sequence works.

### Steps

53. Cut 2020 extrusion to length: 2× 400 mm (X rails), 2× 280 mm (Y rails), 4× 60 mm (corner stiffeners).
54. Assemble the rectangular base frame with corner brackets and T-nuts.
55. Mount steppers at one corner each (one for X, one for Y).
56. Install GT2 belts and pulleys. Tension belts so they ping at a low note when plucked, not loose, not over-tight.
57. Assemble the X carriage on V-slot wheels riding the X rails. Assemble the Y mouse-cradle carriage riding the X carriage.
58. Mount limit switches at X-min and Y-min corners.
59. Flash GRBL (or a hand-written equivalent) to the gantry Arduino Uno. Set steps/mm based on belt pitch and microstepping (200 steps/rev × 16 microsteps / (20 teeth × 2 mm pitch) = 80 steps/mm).
60. Run a homing sequence. The gantry should drive each axis toward its limit switch, back off, re-home, and stop at the origin.

### Acceptance test

Gantry homes itself reliably 10 times in a row. Manual G-code commands G0 X100 Y50 and G0 X0 Y0 move the carriage to the right place, repeatable within 1 mm by ruler measurement.

### Document this week

- Time-lapse the frame assembly (V-slot extrusion construction is visually satisfying).
- Capture the homing sequence — the gantry driving to its limits and re-zeroing is great motion content.
- Post: "the mouse gantry is alive" reel. Show side-by-side: keyboard rig in the background, gantry in the foreground, hint at the integration to come.

## Week 8 — Mouse Cradle and Click

### Goals

- USB optical mouse mounted in a printed cradle on the Y carriage.
- Two SG90 servos with lever arms press the left and right buttons.
- Mouse moves around the gantry and the cursor moves on the MacBook screen accordingly.

### Steps

61. Measure the USB mouse carefully. Design a printed cradle that holds it from underneath, with cutouts for the cable and the left/right buttons.
62. Print the cradle. Test fit. Iterate.
63. Mount two SG90 servos on top of the cradle with printed lever arms positioned over the left and right buttons. Calibrate servo positions for "released" and "pressed".
64. Plug the mouse into the MacBook (it can stay plugged in throughout).
65. In macOS System Settings, disable mouse acceleration (you may need a tool like LinearMouse for this).
66. Move the gantry by G-code; watch the cursor move. Tune the gantry-to-screen ratio.
67. Test CLICK left and CLICK right via servo control.
68. Test HOLD left + MOVE + RELEASE for drag operations.

### Acceptance test

You can manually issue commands to draw a 100 mm × 100 mm square in Preview or a drawing app. All four corners are sharp; lines are straight to within 1 mm by ruler.

### Document this week

- Film the rig drawing a square autonomously — top-down view, screen captured separately, edit both into the same shot.
- Optional: have the rig draw something signature (your handle, the project logo, a TFT champion silhouette).
- Post: "robot draws a square" reel. Surprisingly mesmerizing content.

## Week 9 — Vision Pipeline

### Goals

- Webcam mounted, focus and exposure fixed.
- Calibration ritual (camera intrinsics, screen homography, screen-to-gantry) implemented and persisted.
- Template-matching code runs at 30 FPS on rectified frames.

### Steps

69. Mount the webcam on its arm, position above the MacBook at the angle and height in PRD §4.4.
70. Lock camera settings: open Webcam Settings (or a tool like CameraSettings on macOS), set manual focus, manual exposure, manual white balance. Write down the values.
71. Create host/perception.py with a capture thread using cv2.VideoCapture.
72. Implement the calibration UI: capture one frame, prompt user to click four screen corners, compute homography with cv2.getPerspectiveTransform, save to calibration/homography.json.
73. Implement the screen-to-gantry mapping: display 4 reference dots on the screen, drive gantry to each by hand, record pairs, fit homography, save.
74. Build the template library: take screenshots of UI elements (TextEdit window controls, Preview canvas, etc.) and save as PNGs in templates/.
75. Implement template matching with cv2.matchTemplate, publishing detections to a queue.

### Acceptance test

Capture FPS is ≥25 in production code. Calibration completes in under 5 minutes. After calibration, a template-match script reliably detects a known on-screen icon and prints its screen pixel coordinates with sub-5-pixel jitter.

### Document this week

- Screen-record the calibration ritual: clicking the four screen corners, watching the template detection lock onto a UI icon.
- Explain homography in plain English — "this matrix lets us turn a tilted webcam view into a perfect map of the screen." Visual examples work better than equations.
- Post: "teaching the rig to see" reel.

## Week 10 — Cognition Layer

### Goals

- State machine and task plug-in interface implemented.
- Serial protocol working end-to-end to both Arduinos.
- Typing demo runs autonomously from a single command.

### Steps

76. Implement host/state_machine.py with the states from PRD §5.2.1.
77. Implement host/serial_bus.py: opens both serial ports, exposes send_keyboard() and send_gantry() methods with timeout handling.
78. Implement host/tasks/type_text.py: a task that accepts a string, breaks it into per-character actions, and dispatches them via the keyboard bus.
79. Wire it all together in host/main.py: parse a command-line argument like "type 'hello world'", run the task, exit.
80. Run end-to-end. Watch the rig type "hello world" into a text editor.

### Acceptance test

Running python host/main.py type "your full name and the current date" produces the exact text in TextEdit, without intervention.

### Document this week

- Capture the first end-to-end command: typing a single Python command in your terminal, and the rig responding by physically typing on the keyboard.
- Cut between three shots: terminal command, perception view (webcam), and physical actuation. This is the closed loop visualized.
- Post: "closing the loop — perception to action" reel. Explain the embodied AI concept in one sentence.

## Week 11 — Demos and Acceptance Tests

### Goals

- All three v1 demo task plug-ins implemented.
- All seven acceptance criteria in PRD §7 pass.

### Steps

81. Implement host/tasks/mouse_precision.py: draws a square, then a circle, in a drawing app, using gantry coordinates.
82. Implement host/tasks/fill_form.py: reads a CSV row, navigates a known web form by template matching the form fields, types each value, clicks Submit.
83. Implement a latency benchmark: a small macOS app or web page that flashes a colored square on user command; the agent watches for it and presses a key as fast as possible. Measure end-to-end latency over 100 trials.
84. Run all 7 acceptance criteria. Document pass/fail.
85. Fix any failure modes. Re-run.

### Acceptance test

All 7 PRD §7 acceptance criteria pass in a single fresh session. Latency benchmark median below 100 ms.

### Document this week

- Film all three demos cleanly: typing demo, mouse precision demo, form-filling demo. Multiple takes are fine — pick the best.
- Capture the latency benchmark: visualize the screen flash, the camera seeing it, the keystroke firing. Maybe overlay the measured ms.
- Post: "the rig passes its final exams" reel showing all three demos back-to-back.

## Week 12 — Polish, Documentation, Retro

### Goals

- Rig is cable-managed, labeled, and demo-able to non-technical observers.
- Codebase has a README that lets you (or a future collaborator) rebuild from scratch.
- A short demo video exists.
- You've written a retro on what you learned.

### Steps

86. Tidy all cabling: wire raceway across the back, labels on every connector, slack loops where the gantry needs to move.
87. Write README.md in the project folder. Include: setup instructions, calibration procedure, how to run each demo, troubleshooting common failure modes.
88. Record a demo video showing all three v1 demos end-to-end. Cinematic shots optional, functional shots required.
89. Write a one-page retrospective: what surprised you, what would you do differently, what is the v2 roadmap.

### Acceptance test

A friend who has not seen the project can read the README and identify what each demo does. The video shows the agent doing all three demos without you touching anything mid-run.

### Document this week — the hero post

- Edit a 2–3 minute "12 weeks in" recap video. Open with the empty bench in week 1, end with the rig running all three demos in week 12. Use clips from every weekly post.
- Write the retrospective: what worked, what didn't, what you'd do differently, what v2 looks like. Publish as a long X thread and a pinned GitHub README section.
- Cross-post the hero video to YouTube as well (one-time exception to the X+Instagram rule). Long-form viewers find these via search.
- Tag any tools, parts, or accounts you want to thank. Vendors and parts manufacturers sometimes amplify build content; doesn't hurt to ask.

# 3.5 Documentation Workflow (Weekly Routine)

The weekly content cadence costs roughly three hours total when you follow a routine. The trick is to spread the filming across the whole build week (so you don't face an empty timeline on Sunday) and to compress the editing into one focused session. Pick Sunday evening if you don't already have a fixed posting day.

## Mon–Fri: incidental filming (30 min total)

- Every time you sit down to work, set the phone on the tripod above the bench in record mode for the first 5 minutes. Most of this footage will go unused, but those clips that show "first this happened, then that happened" are the spine of the weekly reel.
- When something visibly works for the first time (a click, a print, a typed letter), film it deliberately with two takes. Wide shot, close-up.
- Capture brief voice memos of the day's lessons. These become voiceover material on Sunday.

## Saturday: pre-edit prep (15 min)

- Dump the week's clips onto your MacBook. Delete obviously unusable ones (out of focus, dropped phone, etc.).
- Outline the weekly reel: three beats — what we tried, what worked, what we shipped. 60–90 seconds total.

## Sunday: editing session (90 min)

- Open CapCut Desktop. Drop the surviving clips into a new project.
- Cut to the three-beat outline. Aim for 5–8 cuts in a 60-second reel. Resist the urge to over-edit.
- Record voiceover in CapCut with the lavalier mic plugged into the phone or MacBook.
- Add captions (CapCut auto-generates from voiceover; check accuracy).
- Export two versions: 1080p vertical 9:16 (Instagram), 1080p horizontal 16:9 (X).

## Sunday: posting (30 min)

- Post the Instagram reel. Caption: one sentence summary, then a short paragraph of detail, then 3–5 relevant hashtags.
- Post the X thread: 3–6 tweets. First tweet has the video and a hook. Subsequent tweets break down the key milestones, link to the GitHub commit range, and link to the PRD/walkthrough.
- Cross-link: Instagram caption mentions the X thread, X thread mentions the Instagram reel.
- Update /docs/weekly-retros.md in the GitHub repo with a 1-paragraph retro for the week. Commit and push.

The hardest week to post is week 5 (soldering) — you will be exhausted. Pre-write your Week 5 caption and X thread outline during week 4, while the energy is still up.

# 4. Common Pitfalls and Field Fixes

Symptom | Likely cause | Fix
Solenoid clicks but key doesn't register | Plate too high (Blush Nano needs only 1.4 mm actuation, but the plunger must clear that distance into the key). | Lower the plate by 0.5–1 mm using the M5 standoffs. Check the silicone tip is not too long. Increase pulse duration from 30 ms to 40 ms.
Blush Nano switch feels mushy or sticky after many strikes | Solenoid striking too hard; low-profile switch bottoming out repeatedly. | Reduce pulse duration to 25 ms. Raise plate by 0.5 mm. If a specific switch is damaged, hot-swap it for a spare.
Random keys firing during typing | Shift register not latching correctly; noise on SH_CP or ST_CP line. | Add a 0.1µF cap from each control line to ground. Shorten control wires. Check star ground.
Arduino resets when many solenoids fire | 12V supply sagging; ground loop pulling 5V down with it. | Verify 12V and 5V are separate buses sharing only one ground star point. Add the 4700µF cap on 12V.
Gantry skips steps under load | A4988 current limit set too low; or accelerations too aggressive. | Adjust the current-limit trimpot on the A4988 (target ~0.7 of motor rated current). Lower acceleration in firmware.
Mouse cursor jitters or drifts on its own | Optical sensor sees inconsistent surface; cradle vibration. | Confirm sensor is 2–3mm above pad. Use a hard plastic mousepad, not cloth. Increase cradle stiffness.
OCR misreads small text | ROI too small or low contrast. | Upsample ROI 3× before OCR. Force the on-screen text to be larger if you control it.
Template matching fails sporadically | Lighting changing across the day. | Lock manual exposure. Close blinds. Add a constant task lamp.
Hand-soldered joint goes intermittent after a week | Cold joint or stranded wire pulled out from solder. | Reflow with flux. For stranded wire, tin the ends before soldering.
Cannot remember which solenoid is on which channel | No labels. | Label every wire pair with a Sharpie at both ends, AS YOU WIRE IT, not later.

# 5. Safety Checklist

Read this before powering anything on for the first time, and review it before each session for the first month of the build. The 12V/40A power supply can sustain a serious arc if a screwdriver lands across its output terminals. Treat it with respect.

- Always disconnect mains power to the PSU before changing wiring on the 12V side. The 12V terminals can deliver enough current to weld a screwdriver to itself.
- Never solder while the board is powered. Even 5V can cause a problem if you slip with the iron.
- Wear safety glasses while soldering and while running the rig (a flying solenoid plunger is unlikely but possible).
- Keep the soldering iron in its stand when not in your hand. Set a 30-minute timer when you start; check on it.
- Solder in a ventilated space. Flux fumes are not friendly. Open a window or use a small fan to pull fumes away.
- Test the E-stop button before every demo session. If it does not cut power within 100 ms, fix it before running the rig.
- Do not leave the rig powered and unattended. The PSU is conservatively rated but mechanical contraptions surprise you.
- Keep liquids off the bench. The mousepad is not a coaster.

# 6. "Am I Actually Done?" Checklist

Tick each item only when you have personally verified it. No theoretical ticks.

- All Wave 1 + Wave 2 parts received and inventoried.
- Soldering kit owned and used on at least one practice board.
- Nuphy Air75 V3 plugged into MacBook and confirmed working as a regular keyboard. 8 spare Blush Nano switches on hand.
- 4×4 prototype plate tested and 4 solenoids reliably press 4 keys at 30 ms pulse duration.
- Full 84-solenoid plate dry-fits over the Nuphy keyboard, including the arrow cluster and right utility column.
- Driver board passes walk-mode test on all 88 channels.
- All 84 solenoids wired and the agent can TYPE arbitrary text.
- Gantry homes reliably and moves to commanded coordinates within 1 mm.
- Mouse cradle holds the mouse, servos click both buttons.
- Drawing demo produces a clean 100 mm × 100 mm square.
- Webcam settings locked manually.
- Calibration files persisted and re-loadable.
- Template-match detector runs at ≥25 FPS.
- State machine runs end-to-end for the typing demo.
- Form-filling demo completes a 5-field web form from a CSV row.
- Latency benchmark median <100 ms over 100 trials.
- E-stop button cuts power to actuators within 100 ms.
- 1-hour endurance typing test passes without faults.
- Cabling is tidy and labeled.
- README is written.
- Demo video is recorded.
- You wrote a retrospective.
- GitHub repo is public and contains: code, firmware, CAD files (Fusion 360 .f3d plus exported STEP and STL), BOM, PRD, walkthrough, README, weekly retros.
- X account has 12+ weekly build-update threads (one per week of the build).
- Instagram account has 12+ weekly build-update reels.
- Final hero recap video is posted and linked from the GitHub README.
- Phone tripod and lavalier mic are owned and used.
- CapCut is installed on phone and MacBook.

Physical AI Agent — Build Walkthrough

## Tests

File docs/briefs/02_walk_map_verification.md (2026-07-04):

# Brief 02 — Flash keyboard_v1, build the MAP, verify with WALK

**Goal:** the soldered board drives real keys with a trusted channel→key map, persisted in EEPROM.

## Context you must hold

- Firmware: `firmware/keyboard_v1/keyboard_v1.ino`. **Read its header before flashing** — power-on rule (USB first, THEN 12V) and `CASCADE_REVERSED` flag (set if WALK shows flipped cell order).
- Protocol: FIRE N → cell(N/8+1)/OUT(N%8+1), sequential by design (canonical Q→IN wiring made this true). TYPE / KEY / CHORD / HOLD / RELEASE; MAP/SAVE/LOAD persist the keymap to EEPROM — **no recompile during solder-time logging.**
- Guards: per-channel 60ms cooldown, MAX_ON=7 (PSU protection — realistic peak ~25A on a 40A supply).
- Host side: `agent/keyboard_driver.py` — `load_map_from_log()` takes a `cell,out,key` CSV and issues MAP+SAVE.

## MAP discipline (canonical — do not improvise)

Position is identity: all leads are identical black. Sharpie the key name beside each landing hole; log `cell · OUT · key` **at solder time**, one line per wire, into the CSV. Cut each wire to length only at the moment it's landed — never pre-cut. WALK mode (fire 0–83, watch which key clicks) is the FINAL verification pass, not the primary bookkeeping.

## Order of operations

1. Flash keyboard_v1 (12V off). Serial sanity: STATUS, then FIRE on a known channel.
2. As each solenoid's low-side wire is landed: log the CSV line immediately.
3. `load_map_from_log()` → MAP+SAVE → LOAD to confirm EEPROM round-trip.
4. WALK pass over all landed channels. Any mismatch → fix the CSV (trust the physical click), re-MAP, re-SAVE.
5. If cell order comes out mirrored → `CASCADE_REVERSED`, reflash, re-WALK.
6. First TYPE of a real sentence — milestone, film it.

## Definition of done

WALK matches MAP 100%; TYPE produces clean text incl. a shifted character (LShift chord); EEPROM survives power cycle; commit + **git push**; CLAUDE.md updated.

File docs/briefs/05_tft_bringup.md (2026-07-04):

# Brief 05 — TFT bring-up: first real game

**Goal:** the physical agent plays a TFT game end-to-end on a cheap brain within budget.

## Pre-game checklist (canonical order — also in `agent/README.md`)

1. `calibrate.py screen` — C920 on tripod, screen-quad rectification saved.
2. `calibrate.py tft` — overlay PNG check. **`tft/layout.json` coords are EYEBALLED DEFAULTS — verify every region against the overlay before trusting.**
3. **Fill `tft/set_data.json`** — it's a placeholder; populate with the live set's champions/traits/costs before any game.
4. Capture `tft/templates/combat_marker.png` — enables the combat-phase hook that skips LLM calls (~70% cost lever). Do not play a paid game without it.
5. `calibrate.py mousekeys` (or `gantry` if Wave 2 is built) — mouse backend calibration.
6. `cd agent && source .venv/bin/activate` — **every new Terminal** (#1 failure mode).

## Run strategy (cost discipline)

- Rehearse free: `--provider ollama` (qwen3-vl:8b local), `--dry-run`/`--still` first, then live keyboard with ollama.
- First paid game: cheap cloud (gemini/deepseek/qwen, ~$0.10–0.50/game), `--budget-usd` set, `--escalate-to anthropic` for augment choices only (or plan `"escalate": true`).
- `play_tft.py` defaults: ollama, 800 turns. Logs land in `agent/logs/` (gitignored) — keep them; they're the tuning corpus.
- Runtime guards already exist: budget/turn/minute stops, stuck detection (frame dHash), validation-error feedback. Use them, don't rebuild them.

## Semantic layer (already written — extend, don't bypass)

`tft_agent.py` maps tft_buy/sell/place/move/bench/roll/level/lock/augment → primitives. Hotkeys D/F/E/W go through the PHYSICAL keyboard; only buys/placements need the mouse. New actions belong in `agent/actions.py` (single vocabulary — add once, works everywhere).

## Debug ladder when something misbehaves

1. `python tests/run_tests.py` (20 tests, zero hardware) — if this fails, the problem is software, stop there.
2. `--dry-run --scripted` — plumbing without LLM or hardware.
3. `--still frame.png` — vision without the camera.
4. ollama live — full loop, $0.
5. Only then paid providers.

## Definition of done

One complete game, total spend logged and under budget, per-turn logs saved, prompt-tuning notes appended to CLAUDE.md; commit + **git push**. Film the first game — this is THE milestone.

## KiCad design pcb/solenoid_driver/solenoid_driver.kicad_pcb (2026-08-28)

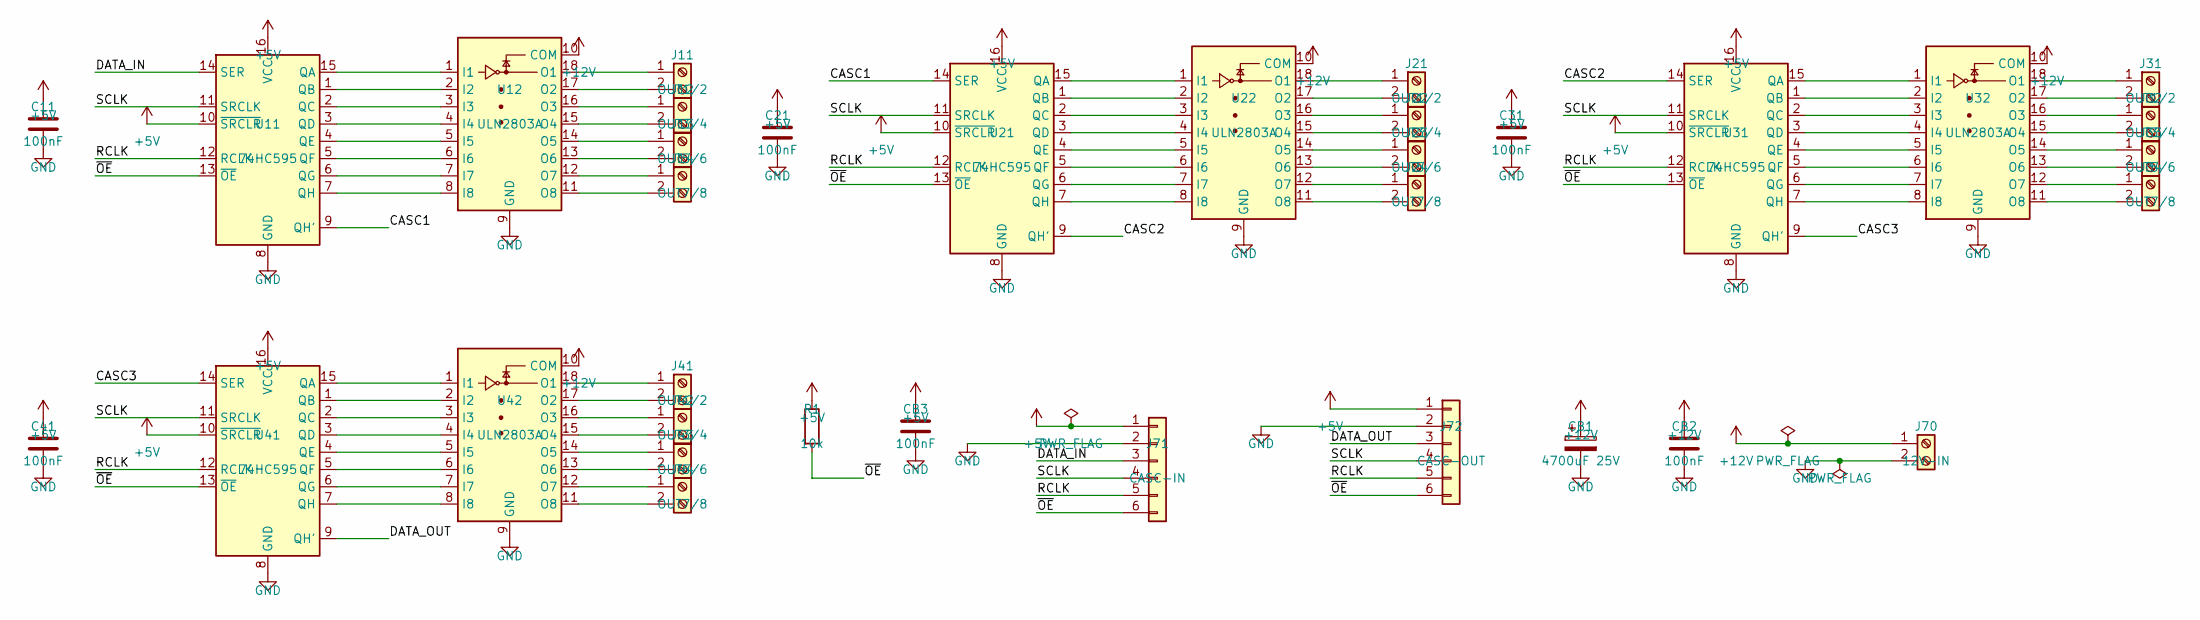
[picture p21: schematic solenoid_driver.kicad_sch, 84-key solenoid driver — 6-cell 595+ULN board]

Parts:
C11, C21, C31, C41: 100nF; C_Disc_D8.0mm_W5.0mm_P5.00mm
CB1: 4700uF 25V; CP_Radial_D18.0mm_P7.50mm
CB2, CB3: 100nF; C_Disc_D8.0mm_W5.0mm_P5.00mm
J11, J21, J31, J41: OUT1/2; TerminalBlock_CUI_TB007-508-02_1x02_P5.08mm_Horizontal
J12, J22, J32, J42: OUT3/4; TerminalBlock_CUI_TB007-508-02_1x02_P5.08mm_Horizontal
J13, J23, J33, J43: OUT5/6; TerminalBlock_CUI_TB007-508-02_1x02_P5.08mm_Horizontal
J14, J24, J34, J44: OUT7/8; TerminalBlock_CUI_TB007-508-02_1x02_P5.08mm_Horizontal
J70: 12V-IN; TerminalBlock_CUI_TB007-508-02_1x02_P5.08mm_Horizontal
J71: CASC-IN; PinHeader_1x06_P2.54mm_Vertical
J72: CASC-OUT; PinHeader_1x06_P2.54mm_Vertical
R1: 10k; R_Axial_DIN0207_L6.3mm_D2.5mm_P10.16mm_Horizontal
U11, U21, U31, U41: 74HC595; DIP-16_W7.62mm
U12, U22, U32, U42: ULN2803A; DIP-18_W7.62mm

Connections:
+5V: C11.1, C21.1, C31.1, C41.1, CB3.1, J71.1, J72.1, R1.1, U11.10 (~SRCLR), U11.16 (VCC), U21.10 (~SRCLR), U21.16 (VCC), U31.10 (~SRCLR), U31.16 (VCC), U41.10 (~SRCLR), U41.16 (VCC)
+12V: CB1.1, CB2.1, J70.1, U12.10 (COM), U22.10 (COM), U32.10 (COM), U42.10 (COM)
/CASC1: U11.9 (QH'), U21.14 (SER)
/CASC2: U21.9 (QH'), U31.14 (SER)
/CASC3: U31.9 (QH'), U41.14 (SER)
/DATA_IN: J71.3, U11.14 (SER)
/DATA_OUT: J72.3, U41.9 (QH')
/RCLK: J71.5, J72.5, U11.12 (RCLK), U21.12 (RCLK), U31.12 (RCLK), U41.12 (RCLK)
/SCLK: J71.4, J72.4, U11.11 (SRCLK), U21.11 (SRCLK), U31.11 (SRCLK), U41.11 (SRCLK)
/~OE: J71.6, J72.6, R1.2, U11.13 (~OE), U21.13 (~OE), U31.13 (~OE), U41.13 (~OE)
GND: C11.2, C21.2, C31.2, C41.2, CB1.2, CB2.2, CB3.2, J70.2, J71.2, J72.2, U11.8 (GND), U12.9 (GND), U21.8 (GND), U22.9 (GND), U31.8 (GND), U32.9 (GND), U41.8 (GND), U42.9 (GND)
unnamed: J11.1, U12.18 (O1)
unnamed: J11.2, U12.17 (O2)
unnamed: J12.1, U12.16 (O3)
unnamed: J12.2, U12.15 (O4)
unnamed: J13.1, U12.14 (O5)
unnamed: J13.2, U12.13 (O6)
unnamed: J14.1, U12.12 (O7)
unnamed: J14.2, U12.11 (O8)
unnamed: J21.1, U22.18 (O1)
unnamed: J21.2, U22.17 (O2)
unnamed: J22.1, U22.16 (O3)
unnamed: J22.2, U22.15 (O4)
unnamed: J23.1, U22.14 (O5)
unnamed: J23.2, U22.13 (O6)
unnamed: J24.1, U22.12 (O7)
unnamed: J24.2, U22.11 (O8)
unnamed: J31.1, U32.18 (O1)
unnamed: J31.2, U32.17 (O2)
unnamed: J32.1, U32.16 (O3)
unnamed: J32.2, U32.15 (O4)
unnamed: J33.1, U32.14 (O5)
unnamed: J33.2, U32.13 (O6)
unnamed: J34.1, U32.12 (O7)
unnamed: J34.2, U32.11 (O8)
unnamed: J41.1, U42.18 (O1)
unnamed: J41.2, U42.17 (O2)
unnamed: J42.1, U42.16 (O3)
unnamed: J42.2, U42.15 (O4)
unnamed: J43.1, U42.14 (O5)
unnamed: J43.2, U42.13 (O6)
unnamed: J44.1, U42.12 (O7)
unnamed: J44.2, U42.11 (O8)
unnamed: U11.15 (QA), U12.1 (I1)
unnamed: U11.1 (QB), U12.2 (I2)
unnamed: U11.2 (QC), U12.3 (I3)
unnamed: U11.3 (QD), U12.4 (I4)
unnamed: U11.4 (QE), U12.5 (I5)
unnamed: U11.5 (QF), U12.6 (I6)
unnamed: U11.6 (QG), U12.7 (I7)
unnamed: U11.7 (QH), U12.8 (I8)
unnamed: U21.15 (QA), U22.1 (I1)
unnamed: U21.1 (QB), U22.2 (I2)
unnamed: U21.2 (QC), U22.3 (I3)
unnamed: U21.3 (QD), U22.4 (I4)
unnamed: U21.4 (QE), U22.5 (I5)
unnamed: U21.5 (QF), U22.6 (I6)
unnamed: U21.6 (QG), U22.7 (I7)
unnamed: U21.7 (QH), U22.8 (I8)
unnamed: U31.15 (QA), U32.1 (I1)
unnamed: U31.1 (QB), U32.2 (I2)
unnamed: U31.2 (QC), U32.3 (I3)
unnamed: U31.3 (QD), U32.4 (I4)
unnamed: U31.4 (QE), U32.5 (I5)
unnamed: U31.5 (QF), U32.6 (I6)
unnamed: U31.6 (QG), U32.7 (I7)
unnamed: U31.7 (QH), U32.8 (I8)
unnamed: U41.15 (QA), U42.1 (I1)
unnamed: U41.1 (QB), U42.2 (I2)
unnamed: U41.2 (QC), U42.3 (I3)
unnamed: U41.3 (QD), U42.4 (I4)
unnamed: U41.4 (QE), U42.5 (I5)
unnamed: U41.5 (QF), U42.6 (I6)
unnamed: U41.6 (QG), U42.7 (I7)
unnamed: U41.7 (QH), U42.8 (I8)

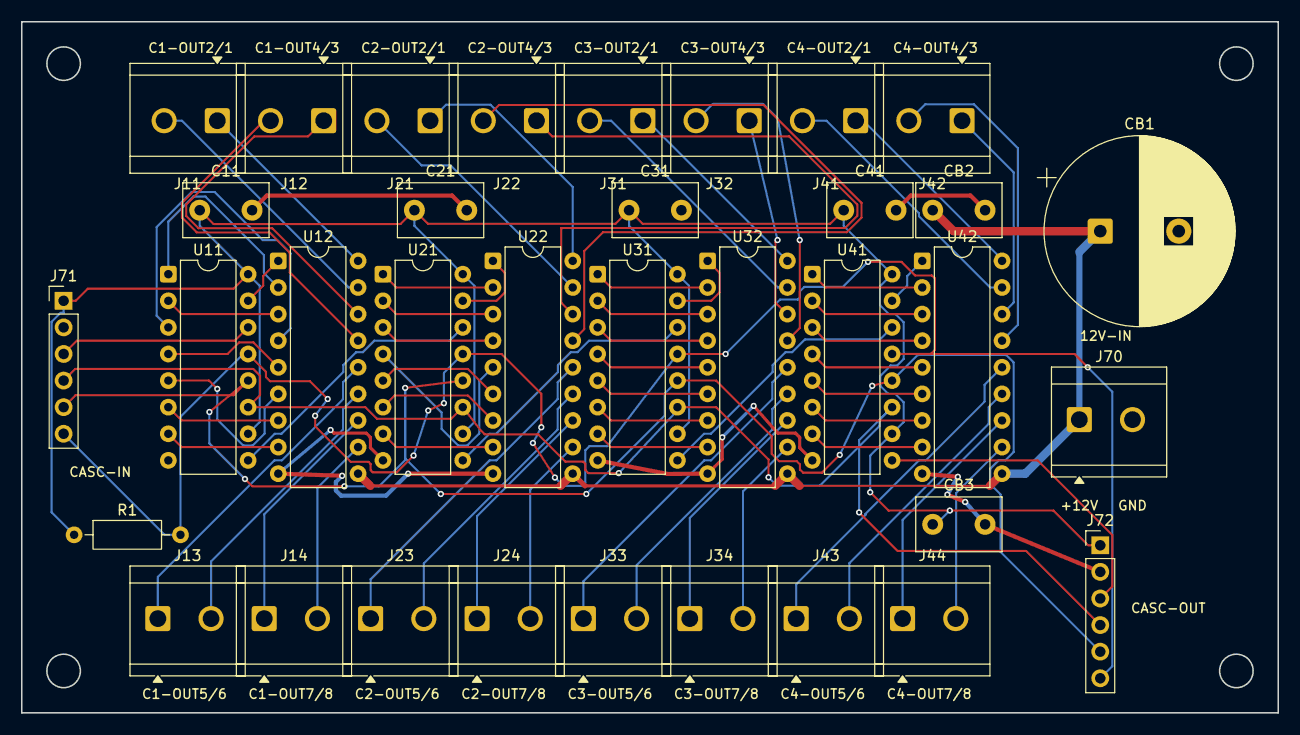
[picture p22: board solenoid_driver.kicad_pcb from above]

Board: 2 copper layers, 120.0 x 66.0 mm, 35 parts (0 on the bottom side), 75 nets.

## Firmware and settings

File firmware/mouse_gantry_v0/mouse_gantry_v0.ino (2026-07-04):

// mouse_gantry_v0.ino
// Wave 2 mouse rig firmware: Cartesian XY gantry carrying a Logitech B100
// (or an animatronic hand riding it), SG90 servos for L/R click.
//
// STATUS: written AHEAD of the Wave 2 hardware decision (gantry favored for
// TFT's drag requirement). The serial protocol below is the contract with
// agent/mouse_driver.py GantryMouse -- if Wave 2 lands on a pantograph or
// another mechanism, keep the protocol and rewrite the motion code only;
// the Python side (and the whole agent) won't notice.
//
// HARDWARE ASSUMPTION (adjust the #defines, nothing else):
//   Arduino Uno/Nano + 2x A4988/DRV8825 on CNC-shield-style pins:
//     X: STEP=2 DIR=5   Y: STEP=3 DIR=6   ENABLE=8 (active LOW, shared)
//     Endstops: X_MIN=9, Y_MIN=10 (NO switches to GND, INPUT_PULLUP)
//     Servos: LEFT=11, RIGHT=12
//   GT2 belt + 20T pulley at 1/8 microstep = 80 steps/mm (the default).
//   No endstops yet? set HAVE_ENDSTOPS 0 -- HOME then just zeros in place
//   (park the carriage at the corner by hand first).
//
// Serial protocol (115200 baud, newline; every command answers OK or ERR):
//   HOME                  seek endstops (or zero in place), position = (0,0)
//   MOVE <x_mm> <y_mm>    absolute move, soft-limited to the pad
//   JOG <dx_mm> <dy_mm>   relative move
//   BTN <L|R> <DOWN|UP>   press / release a click servo (drag support)
//   CLICK <L|R> [ms]      press, hold (default 80ms), release -- atomic
//   SPEED <mm_s>          set cruise speed (default 120, max 250)
//   STATUS                position, speed, button states
//   STOP                  release both buttons, disable motors
//
// SAFETY: same power-on rule family as keyboard_v1 -- USB first, THEN motor
// 12V. Motors are disabled (EN high) until the first motion command.

#include <Servo.h>

// ---- pins (CNC shield convention) ------------------------------------------
const uint8_t PIN_XSTEP = 2, PIN_XDIR = 5;
const uint8_t PIN_YSTEP = 3, PIN_YDIR = 6;
const uint8_t PIN_EN    = 8;                  // active LOW, both drivers
const uint8_t PIN_XMIN  = 9, PIN_YMIN = 10;   // NO -> GND, INPUT_PULLUP
const uint8_t PIN_SRVL  = 11, PIN_SRVR = 12;

// ---- geometry / motion (EDIT to match the build) -----------------------------
#define HAVE_ENDSTOPS   0        // 0 until endstops are wired
const float STEPS_PER_MM = 80.0; // GT2 20T @ 1/8 microstep
const float PAD_W_MM     = 300.0;
const float PAD_H_MM     = 200.0;
const float HOME_BACKOFF = 3.0;  // mm off the switch after homing
float  cruise_mm_s       = 120.0;
const float MAX_MM_S     = 250.0;
const float MIN_MM_S     = 10.0;
const float ACCEL_MM_S2  = 400.0;
// X DIR polarity: 1 if HIGH moves +X (away from the X switch), else 0
#define XDIR_POS 1
#define YDIR_POS 1

// ---- click servos -------------------------------------------------------------
const uint8_t SERVO_REST_L  = 20,  SERVO_PRESS_L = 55;   // tune on the rig
const uint8_t SERVO_REST_R  = 20,  SERVO_PRESS_R = 55;
const uint16_t CLICK_MS_DEFAULT = 80;

Servo servoL, servoR;
bool btnL = false, btnR = false;
float posX = 0, posY = 0;        // believed position, mm
bool motorsOn = false;
char lineBuf[64];
uint8_t lineLen = 0;

// ---- low-level motion ------------------------------------------------------------
void motors(bool on) {
  digitalWrite(PIN_EN, on ? LOW : HIGH);
  if (on && !motorsOn) delay(5);             // driver wake
  motorsOn = on;
}

// Ramped Bresenham line: both axes finish together; trapezoid speed profile.
void moveSteps(long sx, long sy) {
  if (sx == 0 && sy == 0) return;
  motors(true);
  digitalWrite(PIN_XDIR, (sx >= 0) == XDIR_POS ? HIGH : LOW);
  digitalWrite(PIN_YDIR, (sy >= 0) == YDIR_POS ? HIGH : LOW);
  long ax = labs(sx), ay = labs(sy);
  long major = max(ax, ay), minor = min(ax, ay);
  uint8_t pinMaj = (ax >= ay) ? PIN_XSTEP : PIN_YSTEP;
  uint8_t pinMin = (ax >= ay) ? PIN_YSTEP : PIN_XSTEP;

  // speed profile in major-axis steps
  float v = MIN_MM_S, vmax = cruise_mm_s;
  long rampSteps = (long)((vmax * vmax - v * v) /
                          (2 * ACCEL_MM_S2) * STEPS_PER_MM);
  rampSteps = max(1L, min(rampSteps, major / 2));
  long err = major / 2;
  for (long i = 0; i < major; i++) {
    // trapezoid: accelerate, cruise, decelerate
    float frac;
    if (i < rampSteps)              frac = (float)(i + 1) / rampSteps;
    else if (i >= major - rampSteps) frac = (float)(major - i) / rampSteps;
    else                            frac = 1.0;
    float mmps = MIN_MM_S + (vmax - MIN_MM_S) * frac;
    unsigned int usHalf = (unsigned int)(1e6 / (mmps * STEPS_PER_MM) / 2);

    digitalWrite(pinMaj, HIGH);
    err -= minor;
    bool stepMin = false;
    if (err < 0) { err += major; stepMin = true; }
    if (stepMin) digitalWrite(pinMin, HIGH);
    delayMicroseconds(max(usHalf, 3u));
    digitalWrite(pinMaj, LOW);
    if (stepMin) digitalWrite(pinMin, LOW);
    delayMicroseconds(max(usHalf, 3u));
  }
}

void moveToMM(float x, float y) {
  x = constrain(x, 0.0f, PAD_W_MM);
  y = constrain(y, 0.0f, PAD_H_MM);
  long sx = lround((x - posX) * STEPS_PER_MM);
  long sy = lround((y - posY) * STEPS_PER_MM);
  moveSteps(sx, sy);
  posX += sx / STEPS_PER_MM;      // track what we actually stepped
  posY += sy / STEPS_PER_MM;
}

void homeAxes() {
#if HAVE_ENDSTOPS
  motors(true);
  // seek -X then -Y at slow speed until switches close
  digitalWrite(PIN_XDIR, XDIR_POS ? LOW : HIGH);
  while (digitalRead(PIN_XMIN) == HIGH) {
    digitalWrite(PIN_XSTEP, HIGH); delayMicroseconds(400);
    digitalWrite(PIN_XSTEP, LOW);  delayMicroseconds(400);
  }
  digitalWrite(PIN_YDIR, YDIR_POS ? LOW : HIGH);
  while (digitalRead(PIN_YMIN) == HIGH) {
    digitalWrite(PIN_YSTEP, HIGH); delayMicroseconds(400);
    digitalWrite(PIN_YSTEP, LOW);  delayMicroseconds(400);
  }
  posX = posY = 0;
  moveToMM(HOME_BACKOFF, HOME_BACKOFF);
  posX = posY = 0;                 // backoff point is the working origin
#else
  posX = posY = 0;                 // trust the hand-parked corner
#endif
}

// ---- buttons -----------------------------------------------------------------------
void setButton(char which, bool down) {
  if (which == 'L') {
    servoL.write(down ? SERVO_PRESS_L : SERVO_REST_L);
    btnL = down;
  } else {
    servoR.write(down ? SERVO_PRESS_R : SERVO_REST_R);
    btnR = down;
  }
}

// ---- command handling ---------------------------------------------------------------
void handle(char *line) {
  char *cmd = strtok(line, " ");
  if (!cmd) return;

  if (!strcasecmp(cmd, "HOME")) {
    homeAxes();
    Serial.println(F("OK HOME"));

  } else if (!strcasecmp(cmd, "MOVE") || !strcasecmp(cmd, "JOG")) {
    bool rel = !strcasecmp(cmd, "JOG");
    char *sx = strtok(NULL, " "), *sy = strtok(NULL, " ");
    if (!sx || !sy) { Serial.println(F("ERR MOVE <x> <y>")); return; }
    float x = atof(sx), y = atof(sy);
    if (rel) { x += posX; y += posY; }
    moveToMM(x, y);
    Serial.print(F("OK POS ")); Serial.print(posX, 2);
    Serial.print(' '); Serial.println(posY, 2);

  } else if (!strcasecmp(cmd, "BTN")) {
    char *w = strtok(NULL, " "), *st = strtok(NULL, " ");
    if (!w || !st || (toupper(w[0]) != 'L' && toupper(w[0]) != 'R')) {
      Serial.println(F("ERR BTN <L|R> <DOWN|UP>")); return;
    }
    setButton(toupper(w[0]), !strcasecmp(st, "DOWN"));
    Serial.println(F("OK BTN"));

  } else if (!strcasecmp(cmd, "CLICK")) {
    char *w = strtok(NULL, " "), *ms = strtok(NULL, " ");
    char which = w ? toupper(w[0]) : 'L';
    if (which != 'L' && which != 'R') {
      Serial.println(F("ERR CLICK <L|R> [ms]")); return;
    }
    uint16_t hold = ms ? constrain(atoi(ms), 20, 1000) : CLICK_MS_DEFAULT;
    setButton(which, true);  delay(hold);
    setButton(which, false); delay(30);
    Serial.println(F("OK CLICK"));

  } else if (!strcasecmp(cmd, "SPEED")) {
    char *v = strtok(NULL, " ");
    if (v) cruise_mm_s = constrain(atof(v), MIN_MM_S, MAX_MM_S);
    Serial.print(F("OK SPEED ")); Serial.println(cruise_mm_s, 1);

  } else if (!strcasecmp(cmd, "STATUS")) {
    Serial.print(F("OK POS ")); Serial.print(posX, 2);
    Serial.print(' ');          Serial.print(posY, 2);
    Serial.print(F(" SPEED ")); Serial.print(cruise_mm_s, 1);
    Serial.print(F(" L"));      Serial.print(btnL ? F("DOWN") : F("UP"));
    Serial.print(F(" R"));      Serial.println(btnR ? F("DOWN") : F("UP"));

  } else if (!strcasecmp(cmd, "STOP")) {
    setButton('L', false); setButton('R', false);
    motors(false);
    Serial.println(F("OK STOP"));

  } else {
    Serial.print(F("ERR unknown: ")); Serial.println(cmd);
  }
}

void setup() {
  pinMode(PIN_XSTEP, OUTPUT); pinMode(PIN_XDIR, OUTPUT);
  pinMode(PIN_YSTEP, OUTPUT); pinMode(PIN_YDIR, OUTPUT);
  pinMode(PIN_EN, OUTPUT);    digitalWrite(PIN_EN, HIGH);   // disabled
  pinMode(PIN_XMIN, INPUT_PULLUP); pinMode(PIN_YMIN, INPUT_PULLUP);
  servoL.attach(PIN_SRVL); servoR.attach(PIN_SRVR);
  setButton('L', false); setButton('R', false);
  Serial.begin(115200);
  Serial.println(F("mouse_gantry_v0 ready (HOME first)"));
}

void loop() {
  while (Serial.available()) {
    char c = Serial.read();
    if (c == '\n' || c == '\r') {
      if (lineLen) { lineBuf[lineLen] = 0; handle(lineBuf); lineLen = 0; }
    } else if (lineLen < sizeof(lineBuf) - 1) {
      lineBuf[lineLen++] = c;
    }
  }
}

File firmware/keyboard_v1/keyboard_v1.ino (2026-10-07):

// keyboard_v1.ino
// Full 84-key production firmware for the Physical AI Agent.
// Drives 88 solenoid channels via 11x 74HC595 (cascaded) -> 11x ULN2803A.
//
// LINEAGE: scales keyboard_v0 (1 cell / 8 ch) to 11 cells / 88 ch and adds:
//   - named keys (Enter, Bksp, LShift, arrows, F-keys...) from the Air75 layout
//   - TYPE with shift chords: uppercase + shifted symbols press LShift for real
//   - KEY / CHORD / HOLD / RELEASE for modifier combos (e.g. CHORD LCmd+Space)
//   - WALK mode: fire channels in sequence to verify the solder-time MAP log
//   - EEPROM-persisted keymap (SAVE/LOAD) -- edit MAP at runtime, no recompile
//   - per-channel refire cooldown + max-simultaneous-ON guard (PSU/thermal)
//
// CHANNEL NUMBERING (canonical wiring, as-built July 1 2026, all 11 cells):
//   Q0->IN1 ... Q7->IN8, so channel N -> cell (N/8 + 1), ULN OUT(N%8 + 1).
//   FIRE 0  = cell #1 OUT1.  FIRE 87 = cell #11 OUT8.  Channels are sequential;
//   only the channel->KEY map (which key each OUT wire lands on) is data.
//   Cells 1-4 = Board A, 5-8 = Board B, 9-11 = Board C (3-board split).
//
// CASCADE ASSUMPTION: cell #1's 595 is the chip wired to the Mega (DS=D11);
//   each Q7' feeds the next cell's DS. writeShadow() therefore shifts cell 11's
//   byte FIRST and cell 1's byte LAST. If WALK lights cells in reverse order,
//   flip CASCADE_REVERSED to 1 -- do not rewire.
//
// POWER-ON SAFETY (read before first flash on the full plate):
//   A 595 outputs RANDOM data from power-up until setup() clears it. On 84
//   solenoids that's potential random 12V pulses at every boot.
//   FIXED IN HARDWARE on the driver PCB (Jul 2026): R1 (10k) pulls ~OE HIGH
//   = outputs disabled, and ~OE is routed to J71 pin 6 -> Mega D10 (PIN_OE).
//   setup() holds OE HIGH, clears all registers, and only then drives it LOW.
//   CONSEQUENCE: D10 must actually be wired. If ~OE is left floating on the
//   pullup, every channel is disabled and NOTHING FIRES -- serial still
//   responds and WALK still prints, so the symptom looks like dead solenoids.
//   Keep the operating rule anyway: BRING UP THE ARDUINO (USB) FIRST, THEN
//   switch on the 12V rail.
//
// Serial commands (115200 baud, Newline):
//   FIRE <ch> [ms]          fire one channel (0..87)
//   PULSE [ms]              set/get default pulse (22ms = 2x2-validated value)
//   WALK [s [e [ms [gap]]]] fire channels s..e in sequence (default 0..87).
//                           Prints each channel; any serial input aborts.
//                           THE MAP-verification pass: watch which key clicks.
//   TYPE <text>             type text; handles uppercase + shifted symbols
//   KEY <name>              press one named key (KEY Enter, KEY F5, KEY Up)
//   CHORD <a>+<b>[+<c>...]  hold all but last, fire last, release (reverse order)
//   HOLD <name|ch>          hold a channel ON (auto-releases after 10 s)
//   RELEASE <name|ch|ALL>   release held channel(s)
//   MAP [<ch> <key|->]      set/clear/show channel->key map (MAP 12 Enter)
//   SAVE / LOAD             persist / restore keymap to EEPROM
//   LEAD [ms]               head-start delay before TYPE (default 1500)
//   REPEAT <ch> <p> <per> <n> speed test: fire one coil n times every per ms
//
//   FAST-TYPE / STREAM (Oct 3 2026, brief 09 -- the 320 WPM Monkeytype path):
//   Non-blocking, schedule-based. A new key-down every 12000/WPM ms; each coil
//   ON for FPULSE ms; pulses of DIFFERENT keys overlap; the SAME key waits
//   SAMEKEY ms start-to-start (measured Oct 3: 45 ms). Lowercase + space only
//   (no shift in stream). Unmapped chars keep their time slot but fire nothing
//   (so one mapped coil can be tested: FAST jajaja).
//   Q <text>                append text VERBATIM to the stream queue (1024 B);
//                           replies "K <free bytes>" (host waits for K = flow ctl)
//   GO                      start typing the queue after LEAD ms
//   END                     no more text coming: finish when the queue drains
//   FAST <text>             = clear + Q <text> + END + GO  (Serial Monitor test)
//   STOP                    abort now: queue cleared, all coils off, stats
//   WPM [n]                 schedule speed (default 330 = 36.4 ms/char)
//   FPULSE [ms]             stream pulse (default 20, measured Oct 3)
//   SAMEKEY [ms]            same-coil start-to-start minimum (default 45)
//   While a stream runs only Q/END/STOP/ALLOFF/STATUS/WPM/FPULSE/SAMEKEY are
//   accepted (everything else blocks and would wreck the timing -> ERR busy).
//   Finish prints:  DONE slots=.. fired=.. skipped=.. shift=.. same=..
//                   under=.. lateMax=..us ms=.. wpm=..
//   STATUS                  pulse, lead, mapped count, held channels, fire count
//   ALLOFF                  force every channel low
//
// Wiring per cell is unchanged from keyboard_v0 / OneCell guide:
//   595: DS<-prev(or D11), SH_CP=D12 (bused), ST_CP=D13 (bused), MR=+5V,
//        OE=~OE bus -> R1 10k pullup to +5V -> J71 pin 6 -> Mega D10
//        (breadboard rig instead straps OE to GND; then set PIN_OE = 255)
//   ULN: IN1-8 <- Q0-7 canonical, COM(10) -> +12V (flyback -- never skip),
//        GND(9) -> star ground. 0.1uF per chip, bulk cap on the 12V rail.

#include <EEPROM.h>

// ---- pins -------------------------------------------------------------------
const uint8_t PIN_DATA  = 11;   // 595 DS (cell #1)
const uint8_t PIN_CLOCK = 12;   // 595 SH_CP (bused to all cells)
const uint8_t PIN_LATCH = 13;   // 595 ST_CP (bused to all cells)
const uint8_t PIN_OE    = 10;   // 595 OE (active LOW), driver PCB J71 pin 6.
                                // The PCB carries R1, a 10k pullup holding ~OE
                                // HIGH (= outputs DISABLED) at power-up. This pin
                                // MUST be driven or nothing ever fires: setup()
                                // holds it HIGH, clears the registers, then drops
                                // it LOW. Set back to 255 only for the breadboard
                                // rig, where OE is strapped to GND.
#define CASCADE_REVERSED 0      // set 1 if WALK proves cell order is flipped

// ---- geometry ----------------------------------------------------------------
const uint8_t NUM_CELLS    = 11;
const uint8_t NUM_CHANNELS = NUM_CELLS * 8;   // 88 (84 keys + 4 spare)
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

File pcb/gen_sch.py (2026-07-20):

#!/usr/bin/env python3
"""Generate solenoid_driver.kicad_sch — 6-cell 595+ULN driver per brief 06/06a.

Reuses lib_symbols defs (74HC595, ULN2803A, +5V, GND) from the existing file;
adds +12V (clone of +5V), PWR_FLAG, R, C, C_Polarized, Screw_Terminal_01x02,
Conn_01x06 hand-written in the same KiCad-10 grammar. All coords on 2.54 grid.
Footprints embedded per brief 06a so the assign step is already done.
"""
import re, uuid

BASE = 'base.kicad_sch'
OUT  = 'solenoid_driver.kicad_sch'
ROOT_UUID = '18b689b8-b344-482b-a80d-6c06a54d75f2'   # keep: instances path + pcb link

def u(): return str(uuid.uuid4())

# ---------- extract raw lib symbol defs from base ----------
base = open(BASE).read()
def extract(name):
    i = base.index(f'(symbol "{name}"')
    d = 0; j = i
    while True:
        c = base[j]
        if c == '(': d += 1
        elif c == ')':
            d -= 1
            if d == 0: break
        j += 1
    return base[i:j+1]

lib_595 = extract('74xx:74HC595')
lib_uln = extract('Transistor_Array:ULN2803A')
lib_5v  = extract('power:+5V')
lib_gnd = extract('power:GND')
lib_12v = lib_5v.replace('+5V', '+12V')

def mini_prop(name, val, hide=True, at='0 0 0'):
    h = '\n\t\t\t\t(hide yes)' if hide else ''
    return f'''\t\t\t(property "{name}" "{val}"
\t\t\t\t(at {at})
\t\t\t\t(show_name no)
\t\t\t\t(do_not_autoplace no){h}
\t\t\t\t(effects
\t\t\t\t\t(font
\t\t\t\t\t\t(size 1.27 1.27)
\t\t\t\t\t)
\t\t\t\t)
\t\t\t)'''

def lib_pin(ptype, x, y, rot, length, name, number):
    return f'''\t\t\t\t(pin {ptype} line
\t\t\t\t\t(at {x} {y} {rot})
\t\t\t\t\t(length {length})
\t\t\t\t\t(name "{name}"
\t\t\t\t\t\t(effects
\t\t\t\t\t\t\t(font
\t\t\t\t\t\t\t\t(size 1.27 1.27)
\t\t\t\t\t\t\t)
\t\t\t\t\t\t)
\t\t\t\t\t)
\t\t\t\t\t(number "{number}"
\t\t\t\t\t\t(effects
\t\t\t\t\t\t\t(font
\t\t\t\t\t\t\t\t(size 1.27 1.27)
\t\t\t\t\t\t\t)
\t\t\t\t\t\t)
\t\t\t\t\t)
\t\t\t\t)'''

def rect(x1, y1, x2, y2):
    return f'''\t\t\t\t(rectangle
\t\t\t\t\t(start {x1} {y1})
\t\t\t\t\t(end {x2} {y2})
\t\t\t\t\t(stroke
\t\t\t\t\t\t(width 0.254)
\t\t\t\t\t\t(type default)
\t\t\t\t\t)
\t\t\t\t\t(fill
\t\t\t\t\t\t(type background)
\t\t\t\t\t)
\t\t\t\t)'''

def poly(pts):
    p = ' '.join(f'(xy {a} {b})' for a, b in pts)
    return f'''\t\t\t\t(polyline
\t\t\t\t\t(pts
\t\t\t\t\t\t{p}
\t\t\t\t\t)
\t\t\t\t\t(stroke
\t\t\t\t\t\t(width 0.254)
\t\t\t\t\t\t(type default)
\t\t\t\t\t)
\t\t\t\t\t(fill
\t\t\t\t\t\t(type none)
\t\t\t\t\t)
\t\t\t\t)'''

def libsym(name, ref, val, desc, graphics, pins, power=False, hide_pin_text=False):
    short = name.split(':')[1]
    pw = '\n\t\t\t(power global)' if power else ''
    hp = '''
\t\t\t(pin_numbers
\t\t\t\t(hide yes)
\t\t\t)
\t\t\t(pin_names
\t\t\t\t(offset 0)
\t\t\t\t(hide yes)
\t\t\t)''' if hide_pin_text else '''
\t\t\t(pin_names
\t\t\t\t(offset 1.016)
\t\t\t)'''
    g = '\n'.join(graphics)
    p = '\n'.join(pins)
    gblock = f'''\t\t\t(symbol "{short}_0_1"
{g}
\t\t\t)\n''' if graphics else ''
    return f'''\t\t(symbol "{name}"{pw}{hp}
\t\t\t(exclude_from_sim no)
\t\t\t(in_bom yes)
\t\t\t(on_board yes)
\t\t\t(in_pos_files yes)
\t\t\t(duplicate_pin_numbers_are_jumpers no)
{mini_prop("Reference", ref, hide=power, at='0 -3.81 0')}
{mini_prop("Value", val, hide=False, at='0 3.81 0')}
{mini_prop("Footprint", "")}
{mini_prop("Datasheet", "")}
{mini_prop("Description", desc)}
{gblock}\t\t\t(symbol "{short}_1_1"
{p}
\t\t\t)
\t\t\t(embedded_fonts no)
\t\t)'''

lib_flag = libsym('power:PWR_FLAG', '#FLG', 'PWR_FLAG', 'Special symbol for telling ERC where power comes from',
    [poly([(0, 0), (0, 1.27), (-1.016, 1.905), (0, 2.54), (1.016, 1.905), (0, 1.27)])],
    [lib_pin('power_out', 0, 0, 90, 0, '', '1')], power=True, hide_pin_text=True)

lib_r = libsym('Device:R', 'R', 'R', 'Resistor',
    [rect(-1.016, -2.54, 1.016, 2.54)],
    [lib_pin('passive', 0, 5.08, 270, 2.54, '~', '1'),
     lib_pin('passive', 0, -5.08, 90, 2.54, '~', '2')])

cap_plates = [poly([(-2.032, 0.762), (2.032, 0.762)]), poly([(-2.032, -0.762), (2.032, -0.762)])]
lib_c = libsym('Device:C', 'C', 'C', 'Unpolarized capacitor',
    cap_plates,
    [lib_pin('passive', 0, 5.08, 270, 4.318, '~', '1'),
     lib_pin('passive', 0, -5.08, 90, 4.318, '~', '2')])

lib_cp = libsym('Device:C_Polarized', 'C', 'C_Polarized', 'Polarized capacitor, pin 1 = +',
    cap_plates + [poly([(-3.302, 1.778), (-1.778, 1.778)]), poly([(-2.54, 1.016), (-2.54, 2.54)])],
    [lib_pin('passive', 0, 5.08, 270, 4.318, '+', '1'),
     lib_pin('passive', 0, -5.08, 90, 4.318, '-', '2')])

def circ(x, y, r):
    return f'''\t\t\t\t(circle
\t\t\t\t\t(center {x} {y})
\t\t\t\t\t(radius {r})
\t\t\t\t\t(stroke
\t\t\t\t\t\t(width 0.254)
\t\t\t\t\t\t(type default)
\t\t\t\t\t)
\t\t\t\t\t(fill
\t\t\t\t\t\t(type none)
\t\t\t\t\t)
\t\t\t\t)'''

lib_t2 = libsym('Connector:Screw_Terminal_01x02', 'J', 'Screw_Terminal_01x02', 'Screw terminal 2 pos',
    [rect(-1.27, 2.54, 2.54, -5.08), circ(0.635, 0, 0.635), circ(0.635, -2.54, 0.635)],
    [lib_pin('passive', -5.08, 0, 0, 3.81, 'Pin_1', '1'),
     lib_pin('passive', -5.08, -2.54, 0, 3.81, 'Pin_2', '2')])

lib_c6 = libsym('Connector_Generic:Conn_01x06', 'J', 'Conn_01x06', 'Generic 6-pin connector',
    [rect(-1.27, 2.54, 2.54, -15.24)] + [circ(0.635, -2.54*k, 0.635) for k in range(6)],
    [lib_pin('passive', -5.08, -2.54*k, 0, 3.81, f'Pin_{k+1}', str(k+1)) for k in range(6)])

# ---------- placed-item emitters ----------
body = []

def prop(name, val, x, y, hide=False):
    h = '\n\t\t\t(hide yes)' if hide else ''
    return f'''\t\t(property "{name}" "{val}"
\t\t\t(at {x} {y} 0){h}
\t\t\t(show_name no)
\t\t\t(do_not_autoplace no)
\t\t\t(effects
\t\t\t\t(font
\t\t\t\t\t(size 1.27 1.27)
\t\t\t\t)
\t\t\t)
\t\t)'''

def sym(lib_id, ref, val, x, y, rot, npins, footprint='', hide_ref=False, hide_val=False):
    pins = '\n'.join(f'\t\t(pin "{k}"\n\t\t\t(uuid "{u()}")\n\t\t)' for k in range(1, npins+1))
    body.append(f'''\t(symbol
\t\t(lib_id "{lib_id}")
\t\t(at {x} {y} {rot})
\t\t(unit 1)
\t\t(body_style 1)
\t\t(exclude_from_sim no)
\t\t(in_bom yes)
\t\t(on_board yes)
\t\t(in_pos_files yes)
\t\t(dnp no)
\t\t(fields_autoplaced yes)
\t\t(uuid "{u()}")
{prop("Reference", ref, x, y-2.54, hide=hide_ref)}
{prop("Value", val, x, y+2.54, hide=hide_val)}
{prop("Footprint", footprint, x, y, hide=True)}
{prop("Datasheet", "", x, y, hide=True)}
{prop("Description", "", x, y, hide=True)}
{pins}
\t\t(instances
\t\t\t(project "solenoid_driver"
\t\t\t\t(path "/{ROOT_UUID}"
\t\t\t\t\t(reference "{ref}")
\t\t\t\t\t(unit 1)
\t\t\t\t)
\t\t\t)
\t\t)
\t)''')

def wire(x1, y1, x2, y2):
    body.append(f'''\t(wire
\t\t(pts
\t\t\t(xy {x1} {y1}) (xy {x2} {y2})
\t\t)
\t\t(stroke
\t\t\t(width 0)
\t\t\t(type default)
\t\t)
\t\t(uuid "{u()}")
\t)''')

def label(text, x, y):
    body.append(f'''\t(label "{text}"
\t\t(at {x} {y} 0)
\t\t(fields_autoplaced yes)
\t\t(effects
\t\t\t(font
\t\t\t\t(size 1.27 1.27)
\t\t\t)
\t\t\t(justify left bottom)
\t\t)
\t\t(uuid "{u()}")
\t)''')
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

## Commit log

2026-06-25 Initial commit — STL files, Arduino code, READMEs
    [2x2 Prototype FINALFINALFINAL.dxf, 2x2 Prototype V3.stl, 2x2 Prototype VFINAL.stl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]
2026-06-25 Keep STLs and firmware, remove docs
    [2x2 Prototype FINALFINALFINAL.dxf, Content_Calendar.xlsx, Full_84Key_Hole_Coordinates.csv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]
2026-07-02 Pre-cleanup snapshot: all files before folder reorganization
    [2x2 Prototype FINALFINALFINAL.dxf, Content_Calendar.xlsx, Full_84Key_Hole_Coordinates.csv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]
2026-07-02 Folder cleanup: remove superseded/abandoned files, add Project_Timeline.md, update CLAUDE.md
    [Plate_Holes_Air75.dxf, Plate_Left.stl, Plate_Right.stl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]
2026-07-02 Firmware v1 (88ch, chords, WALK, EEPROM map) + agent stack (driver/vision/loop); pre-trip milestone
2026-07-04 Production agent stack: runtime engine, mouse drivers (mousekeys/gantry), TFT layer, calibration, gantry firmware, 20-test ladder
2026-07-05 CLAUDE.md: Opus session — push + Mac test verification, close 2 UNVERIFIED items
2026-07-07 84-key plate populated (6-wall as-built, brief 03 shelved); Jul 7 session record
2026-07-14 Driver route: PCB confirmed (brief 06); breadboard fire test PASSED (UNVERIFIED #3 closed); cell #1 soldered; Jul 10+13 session records
2026-07-20 Schematic ERC clean, nets verified, CUI terminal footprints
    [base.kicad_sch, solenoid_driver.kicad_pcb, solenoid_driver.kicad_sch]
2026-07-23 PCB: trim to 4 cells (3-board plan); place cells + Edge.Cuts (120x66mm); flip top-row terminals mouths-outboard
    [solenoid_driver.kicad_pcb, solenoid_driver.kicad_sch]
2026-07-24 PCB complete: routing closed, GND repaired, +12V widened, silkscreen labels, DRC clean
    [solenoid_driver.dsn]
2026-07-27 PCB: add +12V/GND polarity silkscreen at J70 (prevents reversed-supply chip kill)
2026-07-27 Pre-order audit: silk digit order (left digit = left screw); PIN_OE=10; Jul 26 records
2026-07-27 PCB ORDERED: Gerbers plotted+audited, silk digit order fixed, PIN_OE=10, Jul 26 records
    [solenoid_driver-B_Cu.gbr, solenoid_driver-B_Mask.gbr, solenoid_driver-Edge_Cuts.gbr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]
2026-08-28 Aug sprint record: cad/ Fusion coupon generator + geometry verifier; deck-height correction Z42->Z58 (plunger not body, brief 08 amended); media/ (plate stills, b-roll, cell cascade clips); Aug 2 ses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
    [solenoid_driver.kicad_pcb, solenoid_driver.kicad_sch]
2026-09-21 Sep 20: project redefined (self-playing keyboard, TFT+Wave2 dropped); BOARD A built and passed full continuity gate
2026-09-21 Sep 21: BOARD A ALIVE - 32/32 channels switching, PIN_OE=10 proven on hardware; meter-mode correction (diode not continuity); session card updated (connectorized cascade, full 32-channel sweep)
    Claude-Session: https://claude.ai/code/session_01Uh1P6jinyzXg4SCgEGN7Y7
2026-09-25 Sep 25: printed shelf + barrier-strip power plan; B/C/chain session card
2026-09-26 Sep 25: ALL 88 CHANNELS PROVEN - boards B+C gated, chain A->B->C passed; reversed-5V incident (no damage)
2026-09-27 Sep 26: overhead table designed - STLs, per-solenoid lead holes, strip sandwich, 12V plan
    [Table_Left.stl, Table_Leg.stl, Table_Right.stl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]
2026-09-29 Sep 29: table printed, PCB post fit confirmed, legs hot-glued
2026-10-01 Sep 30: legs + strips glued, knob dot 2, resume at first fire
    [Driver_PH1_100.stl, Driver_PH1_110.stl, Driver_PH1_90.stl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]
2026-10-03 Oct 3: first 12V fire; speed test GO (20ms pulse, 45ms same-key); REPEAT command
2026-10-05 Monkeytype: 340 @100%, 541 @99% (WPM 600 cap)
    [Knob_D11_PH1_100.stl, Knob_D12_dot2_x12.stl, smallahhdriverX12.stl]
2026-10-07 Oct 6-7: full key map (67 keys), Minus alias fix, Tetris plan (brief 10)
    [keyboard_v1.ino]
